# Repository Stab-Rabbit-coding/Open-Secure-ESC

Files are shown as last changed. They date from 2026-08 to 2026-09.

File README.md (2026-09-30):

# Open Source Trustworthy Electronic Speed Control

All builds:

MCU: **TI MSPM0G3518-Q1**, package RHB (VQFN-32, 5x5mm), orderable `M0G3518QRHBRQ1` [44] — pin map VERIFIED, standard package for all builds as of 2026-09-06 (`docs/solutions/architecture-patterns/bom-creepage-audit-can485-faraday.md` finding #1; supersedes the PM/LQFP-64 package, same die, ~4x smaller footprint). Supersedes the NXP S32K144 [31] as of 2026-08-10 (`TODO.md` §13.1; migration record in [`docs/HANDOFF-mcu-swap-s32k144-to-mspm0g3518.md`](docs/HANDOFF-mcu-swap-s32k144-to-mspm0g3518.md)), for its AES-128/256 accelerator with GCM/CMAC and hardware keystore, which lifted the AES-128 ceiling the S32K144's SHE-compliant CSEc imposed.

> **The two lines below still describe the S32K144 and its CSEc, which is no longer the MCU in any build.** They are left in place because the swap's *security* consequences are unfinished work, not a documentation lag — `docs/secure-element-architecture.md` has not yet been revisited (`TODO.md` §13.1.e), so rewriting the summary here would assert a conclusion nobody has reached. Treat every CSEc statement below as describing a superseded design until §13.1.e closes. The OPTIGA Trust M's role is unaffected: the MSPM0's AES engine is still symmetric, so the asymmetric layer is still required.

Message authentication: on-chip CSEc (Cryptographic Services Engine, SHE-compliant) security module built into the S32K144 [31] — no discrete TPM (the previously used Infineon SLB9672 [2] has been dropped from this design)
Root of trust: Infineon OPTIGA™ Trust M V3 secure element [45] over I²C (schematic `U2`) — device identity (ECDSA over a fab-provisioned key + X.509 certificate) and ephemeral session-key agreement (ECDHE). This is a secure element, **not** a TPM: it supplies the asymmetric layer CSEc structurally lacks, while CSEc keeps the per-frame AES-128 CMAC hot path. The split, and the 5 s security-monitor budget that forces it, are documented in [`docs/secure-element-architecture.md`](docs/secure-element-architecture.md)

Build Options:

* Motor speed sensor: ADC/DIO/SPI shaft sensor input (Hall / encoder / analog tach / magnetic absolute SSI-SPI, e.g. AEAT-8800-Q24 [64])
* Motor type: Brushed (Tier-1 integrated H-bridge DRV8874-Q1 [63]) / Brushless
* Holding brake: None (default) / Low-side solenoid driver, spring-applied (de-energised = engaged; TPL7407L [66]) — see `docs/decision-matrix.xlsx` "Holding Brake"
* Voltage: 2S, 4S, 6S, 8S, 12S
* Amperage: 10A, 20A, 30A, 40A, 50A, 80A, 120A
* Protocol: PWM, SBus, DBus, UART, TTL, SPI, RS-232 [3], RS-485 [4], CAN2.0 [5], CAN-FD [6], MIL-STD-1553B [7]
* Control: Open, Closed-Diff, Closed-PID
* EMI Hardening: None, Isolation, Grounding, Faraday
* Wire Egress: Opposite-end (default), Same-end opposite faces (both conductor groups leave one board end, phases on F.Cu and pack on B.Cu, shielded by the inner GND planes)
* Form Factor: Flat (default), Faceted rigid-flex (for mounting inside a curved host; strip width and sagitta derive from the host bore radius — see `docs/tools/strip_width.py`)
* Ingress & environmental protection: Splash/spray variants (target IPX4–IPX6, IEC 60529 [56]) air-cooled via an open aspirated path; Sealed/immersion variants (target IPX7–IPX8, up to NEMA 6P equivalent) shall use a metal conduction cooling path with no air exchange — these are two distinct mechanical designs, not one IP-rating dial (see `docs/design-waterproofing-and-thermal-management.md`).

## Repository layout

* `symbols/` — shared KiCad symbol library (one `.kicad_sym` per component),
  generated from citable pin specs; see `symbols/README.md`.
* `builds/<voltage>/<amperage>/<variant>/` — per-build instantiation of the
  axis options above: a descriptive `README.md` (BOM drawn from
  `docs/decision-matrix.xlsx`, with citations), a `kicad/` subfolder
  (schematic + shared-library wiring), and a `gerbers/` subfolder
  (fabrication output once a layout exists). Example:
  `builds/6s/50A/CAN_485_faraday/`.
* `docs/decision-matrix.xlsx` — per-axis BOM/workflow decision matrix that
  every build folder is generated from.
* `PROJECT_INDEX.md` — index of every active folder and file, with the
  conventions worth knowing before editing.

## License

Licensed under the CERN Open Hardware Licence Version 2 — Permissive
(CERN-OHL-P v2) [8]. See `LICENSE`.

## Governance

Contributions (human or AI) are governed by `AGENTS.md`. All citations
above are indexed in `REFERENCES.md`. Work is tracked in `TODO.md`.

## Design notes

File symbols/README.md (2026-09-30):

# symbols/ — Shared KiCad Symbol Library

Governed by `AGENTS.md`. One `.kicad_sym` file per component, generated (not
hand-edited) from a citable JSON pin spec. This folder is shared across every
`builds/<voltage>/<amperage>/<variant>/` build — a build's `kicad/` folder
references these files instead of re-deriving or re-drawing pinouts, which is
the token-optimized part of the workflow: sourcing a datasheet pinout once
here is reusable for every future build that needs the same part.

## Layout

```text
symbols/
  <PART>.kicad_sym      generated symbol library, one component per file
  specs/<PART>.json      pin spec the symbol was generated from (source of truth)
  tools/gen_kicad_symbol.py   generator: JSON spec -> .kicad_sym
```

Never hand-edit a `.kicad_sym` file directly (except cosmetic repositioning in
the KiCad Symbol Editor, which does not change pin numbers/names). If a pin
map changes, edit the JSON spec and regenerate:

```bash
cd symbols/tools
python3 gen_kicad_symbol.py ../specs/<PART>.json -o ..
```

Regenerate everything: `python3 gen_kicad_symbol.py ../specs/*.json -o ..`

Uses `kiutils` when it is installed (`pip install kiutils`; generated and round-trip-validated
against kiutils 1.4.8). When it is not importable the generator falls back to a
built-in S-expression emitter that writes the same file shape byte for byte
(checked 2026-09-17 against the committed `OPTIGA_TRUST_M` and `BLM15HD182SN1D`
symbols); validate the output with `kicad-cli sym export svg <PART>.kicad_sym` on
such machines.

## Adding a new component (the reusable part of this workflow)

1. Locate the component's primary datasheet (manufacturer PDF), per
   `AGENTS.md` SS1.1. If a local copy exists under `docs/datasheets/`, extract
   the pin table from it directly (e.g. with `pypdf`) rather than trusting
   memory or a secondary source.
2. Add/reuse a citation tag in `REFERENCES.md` per `AGENTS.md` SS2.
3. Write `symbols/specs/<PART>.json`:
   - `pins`: list of `{"num", "name", "etype", "side"}`. `etype` is a KiCad
     electrical pin type (`input`, `output`, `bidirectional`, `tri_state`,
     `passive`, `power_in`, `power_out`, `open_collector`, `no_connect`, ...).
     `side` is `left` / `right` / `top` / `bottom` — a layout hint, not a
     datasheet claim (rearrange freely in the KiCad Symbol Editor).
   - `citation`: REFERENCES.md tag(s), e.g. `"[9]"`.
   - `verification`: state plainly whether pin **numbers** came from a
     primary-source pin table (`VERIFIED`, cite page/table) or are
     placeholders because no primary source was reachable
     (`UNVERIFIED PLACEHOLDER PIN MAP`, per `AGENTS.md` SS1.3/SS3 — never
     silently presented as settled).
4. Run the generator, then round-trip-validate:

   ```bash
   python3 -c "from kiutils.symbol import SymbolLib; SymbolLib.from_file('../<PART>.kicad_sym')"
   ```

5. Reference the new file from the build's `kicad/sym-lib-table` (see below).

## Per-component status

| File | Citation | Pin-map status |
| --- | --- | --- |
| `S32K144.kicad_sym` | [31] | Feature-level facts VERIFIED; pin **numbers** UNVERIFIED PLACEHOLDER (local datasheet defers physical pinout to the S32K1xx Reference Manual, not obtained — see spec `verification` field, `TODO.md`) |
| `OPTIGA_TRUST_M.kicad_sym` | [45] | VERIFIED (full 10-pin PG-USON-10-2,-4 map, local datasheet p.17 Table 6). **Footprint deliberately blank** — no KiCad 9 standard footprint matches this 3×3 mm / 0.5 mm-pitch package; size one from p.15 Fig. 6 before layout |
| `ADM2582E_ADM2587E.kicad_sym` | [4], [9] | VERIFIED (full 20-pin); part selection itself still "Candidate" in `docs/decision-matrix.xlsx` |
| `ADM3055E_ADM3057E.kicad_sym` | [6], [10] | VERIFIED (full 20-pin); part selection itself still "Candidate" |
| `MSPM0G3518_Q1_RHB_TILT.kicad_sym` | [44] | VERIFIED (all 32 RHB pins, [44] Fig. 6-6 / Table 6-2 read 2026-09-17); the RHB MCU with pins named by their role in `builds/6s/10A/BRUSHED_CAN_485_isolation/` — includes PA7/PA22/PA26/PA27, which `MSPM0G3518_Q1_RHB` omits |
| `DRV8874_Q1.kicad_sym` | [62], [63] | VERIFIED (full 16-pin PWP map, [63] Sec. 5, cross-checked against [62]); footprint `Open_Secure_ESC:TI_PWP0016J_…` from TI's own land-pattern sheet (`tools/gen_ti_powerpad_footprints.py`). Tier-1 brushed bridge, first used by `builds/6s/10A/BRUSHED_CAN_485_isolation/` |
| `TPS54560B.kicad_sym` | [65] | VERIFIED (full 8-pin DDA map, [65] Sec. 5); footprint `Open_Secure_ESC:TI_DDA0008B_…` from TI's land-pattern sheet. Motor-rail buck of the 6S/10A brushed build; inductor/diode/compensation not selected by the spec |
| `TPL7407L.kicad_sym` | [66] | VERIFIED (full 16-pin map, [66] Sec. 5); footprint is KiCad stock `Package_SO:TSSOP-16_4.4x5mm_P0.65mm` checked against the PW outline (JEDEC MO-153 IPC land, flagged per AGENTS.md Sec. 4). Brake-solenoid low-side driver |
| `AEAT_8800_Q24.kicad_sym` | [64] | VERIFIED (full 24-pin map, [64] Pinout Description; EP = VSS not modelled as a pin); footprint is KiCad stock `Package_DFN_QFN:QFN-24-1EP_5x5mm_P0.65mm_EP3.25x3.25mm` checked against [64] Fig. 16 dimensions; Broadcom's own land pattern (Fig. 17, raster) NOT verified — TODO.md 18.5. Off-board sensor daughter part |
| `DRV8353S.kicad_sym` | [21] | VERIFIED (full 40-pin, RTA/WQFN package; local datasheet). **2026-08-15: pin 41 `PAD` added** for the exposed thermal pad, tied to GND — without it the footprint's pad 41 imported with no net, i.e. an isolated copper island under the power stage. The GND assignment is an engineering default, not a datasheet value. Footprint now `Open_Secure_ESC:TI_RTA0040B_WQFN-40_6x6mm_P0.5mm_EP4.15x4.15mm` |
| `INA240.kicad_sym` | [22] | VERIFIED (full 8-pin, D/SOIC-8 package; local datasheet) |
| `IRFB4110PBF.kicad_sym` | [20] | Standard TO-220AB G/D/S pinout convention; ratings VERIFIED (local datasheet) |
| `WSLP2512.kicad_sym` | [23] | Generic 2-terminal chip pinout; values VERIFIED (local datasheet) |
| `INR21700_P42A.kicad_sym` | [14] | Generic 2-terminal cell pinout; values VERIFIED (local datasheet) |
| `WE_SHC_3671375.kicad_sym` | [15], [19] | Mechanical shield **cover** — no functional schematic pins (placeholder GND-bond pin only); dimensions VERIFIED (local datasheet); pairs with the frame below. **Intentionally has NO footprint**: the cover clips onto the frame and is not soldered, so its datasheet publishes no land pattern. Placed on schematics as BOM-only, excluded from the board |
| `WE_SHC_3670375.kicad_sym` | [15], [19], [30] | Mechanical shield **frame** — the piece actually soldered; dimensions VERIFIED (local datasheet). Footprint `Open_Secure_ESC:Wurth_WE-SHC_3670375_Frame_29.3x37.5mm` reproduces Wurth's own Recommended Land Pattern |

"UNVERIFIED PLACEHOLDER" pin maps shall not be sent to fab — see each
`specs/*.json` `verification` field and `TODO.md` 1.10 for what would need to
be resolved first (a working fetch path or a manually obtained primary PDF).

**2026-08-03: MCU/TPM swap.** `MSPM0G3507.kicad_sym`/`specs/MSPM0G3507.json`
(project MCU, REFERENCES.md [1]) and `SLB9672.kicad_sym`/`specs/SLB9672.json`
(external TPM, REFERENCES.md [2]) were removed from this folder. The project
MCU changed to the NXP S32K144 (`S32K144.kicad_sym`, [31] above), whose
on-chip CSEc security module now provides message authentication in place of
the discrete SLB9672 TPM — see root `README.md` and
`builds/6s/50A/CAN_485_faraday/README.md`. Both REFERENCES.md entries [1]
and [2] are retained (never repurposed, per `AGENTS.md` §2.5) and marked
superseded/dropped there; their local datasheet PDFs under
`docs/datasheets/` are also kept so those citation records stay resolvable.

**2026-08-09: secure element added (not a TPM reinstatement).**
`OPTIGA_TRUST_M.kicad_sym`/`specs/OPTIGA_TRUST_M.json` ([45], Infineon
OPTIGA™ Trust M V3, sales code SLS 32AIA010ML) joins this library. It is an
**I2C secure element, a different device class from the dropped SLB9672
TPM 2.0** ([2]) — it is adopted for the asymmetric PKI capability the
S32K144's symmetric-only CSEc structurally cannot provide, and it runs
*alongside* CSEc rather than replacing it. The 2026-08-03 decision above
stands: CSEc still owns per-frame message authentication. See
`docs/secure-element-architecture.md`.

Housekeeping done in the same pass: `SLB9672_TPM.kicad_sym` was deleted.
That file was an orphan — the 2026-08-03 note above already declared the
SLB9672 symbol removed, and no `specs/SLB9672.json` exists, so the file
could not be regenerated, was referenced by nothing, and contradicted both
this README and `REFERENCES.md` [2]. Removing it makes the tree match what
those two documents already said.

## footprints/ — this repo's own land patterns

`footprints/Open_Secure_ESC.pretty/` holds footprints for packages KiCad 9.0
does not ship. Each one is generated by a script in `tools/`, and each
script's docstring records exactly which drawing every dimension came from
and which numbers are derivations rather than manufacturer values — the same
standard `specs/*.json` applies to pin maps.

| Footprint | For | Source of the land pattern |
| --- | --- | --- |
| `Infineon_PG-USON-10-2-4_3x3mm_P0.5mm_EP1.7x2.5mm` | OPTIGA Trust M (U2) | Package dimensions from [45] p.15 Fig. 6. Infineon publishes **no** land pattern, so the fillets are an **IPC-7351-style derivation** — an engineering judgment call per `AGENTS.md` §4 |
| `Texas_DGS0028A_VSSOP-28_3x7.1mm_P0.5mm` | superseded MCU package | TI package drawing |
| `TI_RTA0040B_WQFN-40_6x6mm_P0.5mm_EP4.15x4.15mm` | DRV8353S gate driver (U5) | **TI's own** EXAMPLE BOARD LAYOUT and EXAMPLE STENCIL DESIGN sheets, drawing 4219112/A in [21] — manufacturer values, not a derivation |
| `Wurth_WE-SHC_3670375_Frame_29.3x37.5mm` | Faraday shield frame (SH1) | **Wurth's own** Recommended Land Pattern, [30] p.1 rev. ViM 002.000 — manufacturer values. Hole *plating* is the one engineering default |

Two of these land patterns are printed as vector drawings whose callouts do
not survive `pdftotext`. Where that happened the sheet was rendered at
300–400 dpi and measured, and the reading was then **cross-checked against an
independent dimension on the same drawing** rather than trusted on its own —
see each generator's docstring for the specific checks. That cross-check is
what separates a measured value from a guessed one under `AGENTS.md` §1.3.

**Toshiba land patterns live in the CATALOG, not the datasheet.** The
TPHR8504PL part datasheet has no land pattern -- all 10 pages were searched
and the words "land", "mounting" and "recommend" do not appear. Toshiba
publishes them in the *MOSFET Product Catalog* (REFERENCES.md [50], local
copy `docs/datasheets/TPHR8504PL_catalog_20260706_ALQ00024.pdf`), whose
**p.46 "Surface Mount Type"** tabulates package dimensions and land patterns
side by side for the whole surface-mount family -- DSOP Advance(WF)L/M, SOP
Advance, SOP Advance(N), SOP Advance(E), SOP Advance(EWF). Use it for **any**
Toshiba MOSFET package this repo adopts; do not derive one from the package
drawing when the catalog has the real figure. The first pass at
`gen_tphr8504pl_footprint.py` did derive one IPC-7351-style, and it was 46%
short on drain-land area and 86% short on lead-pad area against Toshiba's
published values.

**Watch the reference datum.** TI's RTA0040B sheet dimensions `2X (5.8)` as
the **centre-to-centre** distance between opposite pad rows, not the outer
copper extent. Reading it as the outer extent moves every pad 0.3 mm inward
and overlaps the corner pads — a dead short between pin 1 (CPL) and pin 40
(VGLS). DRC caught it; inspection had not.

## Open_Secure_ESC_Generic.kicad_sym — generic support symbols

R, C, C_Polarized, Conn_01x02/03/04 and PWR_FLAG, as authored by
`builds/*/kicad/tools/genlib.py`. These had previously been stored in
schematics under KiCad's own `Device:`, `Connector_Generic:` and `power:`
library names even though their pin geometry differs from KiCad's parts
(`Device:R` pin 1 sits at y = 6.35 here against y = 3.81 in KiCad 9.0),
which made every placed instance raise a `lib_symbol_mismatch`. They live
here now so that a schematic matches the library it names. Their *values*
remain engineering defaults, not datasheet-sourced.

## Using this library from a build

Add a project-relative library table entry (see
`builds/6s/50A/CAN_485_faraday/kicad/sym-lib-table` for a working example)
pointing at this shared folder. `${KIPRJMOD}` is the folder containing the
`.kicad_pro`/`.kicad_sch`; for a build at
`builds/<voltage>/<amperage>/<variant>/kicad/`, that is 5 levels above
`symbols/`:

```text
(lib (name "open_secure_esc")(type "KiCad")(uri "${KIPRJMOD}/../../../../../symbols/S32K144.kicad_sym")(options "")(descr ""))
```

One `(lib ...)` line per `.kicad_sym` file needed by that build — do not copy
symbol files into a build folder; reference the shared copy so a pin-map
correction only has to happen once.

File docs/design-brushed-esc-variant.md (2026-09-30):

# Design Decision: Brushed ESC Variant — Physical and Firmware Integration

Status: DRAFT (authoring complete) — **first instance built 2026-09-17:** `builds/6s/10A/BRUSHED_CAN_485_isolation/` (Tier-1 integrated H-bridge DRV8874-Q1 [63]; schematic + BOM readiness, `TODO.md` §18). That build's README resolves the fail-safe question below for itself (brake engaged, motor coasting) and carries the brushed firmware requirements.
Applies to: Brushed-ESC build variants (new branch of builds)
Governing rules: AGENTS.md §1–§3 — verify all part claims against primary datasheets; mark `UNVERIFIED` when not available.

Summary

- Provide a design decision record describing how the brushed-ESC variant differs from brushless designs at the schematic, BOM, PCB, and firmware levels, and document safety/protection specifics.

Why support brushed motors

- Brushed motors remain common in many industrial and hobbyist use cases; supporting a dedicated H-bridge variant increases product applicability. Brushed variant simplifies commutation logic but requires careful H-bridge and protection design.

Electrical architecture (high level)

- Replace 3-phase inverter drive + gate-driver stage with a single H-bridge (half-bridge pair) sized for target amperage tier.
- Provide current sensing, dead-time control, and flyback/clamping protection appropriate for inductive motor loads and regenerative events.
- Include direction control signal and PWM input (single channel + direction) in firmware mapping.

Power-stage components & protection (to be VERIFIED)

- H-bridge MOSFETs or integrated H-bridge ICs sized per amperage tier. Tier 1 (2S–6S, 10–20 A) is now the TI DRV8874-Q1 [63] (datasheet local, VERIFIED); Tier-2/3 discrete-FET candidates remain UNVERIFIED until their datasheets are added (see `docs/OpenSecureESC-Brushed-Specifications.md` §1).
- Freewheeling / flyback diodes or synchronous MOSFET conduction strategy: the design shall handle regenerative currents; include regenerative path to bus or clamp/regulator and report to firmware.
- RC snubbers, TVS for transients, and precharge/soft-start for large motor inductance loads.
- Current sensing: shunt + amplifier or integrated current-sense filter placement to provide overcurrent detection and closed-loop current limit.

Schematic & PCB layout notes

- H-bridge placed close to power connectors; copper pour for heat dissipation.
- Thermal considerations: footprint for thermal vias, heatpad and heatsink provision.
- Keep sensitive analog/logic routing (speed-sensor, ADC, encoder lines) physically separated and shielded from switching nodes and gate traces.
- Provide component footprints and mechanical constraints in `builds/<voltage>/<amperage>/BRUSHED_<variant>/kicad/`.

Firmware implications

- Add brushed control code path:

  - PWM + direction mapping
  - Closed-loop speed control via speed sensor (see design-speed-sensor-integration.md)
  - Current-limiting and regenerative handling logic
  - Dead-time configuration and MOSFET gate timing safe defaults

- Define test vectors and unit tests for:

  - Direction change safety (ensure motor spins down or safe transition)
  - Short-circuit and overcurrent cutoff behavior
  - Regeneration absorption/limiting

Safety & failure modes

> **CAUTION:** H-bridge cross-conduction (shoot-through) drives simultaneous high-side/low-side
> conduction, which can destroy the power MOSFETs within microseconds and presents a fire risk
> from the resulting overcurrent. Cross-conduction detection shall hard-disable PWM immediately
> on assertion; do not rely on current-sense overthreshold handling alone to catch this case.

- Define safe-state on faults (fail-safe vs fail-operational decision required; reference to `TODO.md` 12.3 and project safety requirements).
- On MOSFET cross-conduction detection: hard disable PWM and assert fault.
- On current-sense overthreshold: limit duty cycle, then trip if persists.

Acceptance checklist (before layout/fab)

- H-bridge ERC clean
- Current-sense integrated and validated in schematic
- Dead-time validated in simulation/tooling
- Thermal analysis for MOSFETs and heatsinking
- Firmware test harness for brushed flow
- BOM lines for H-bridge parts present and each has a `REFERENCES.md` entry (IEEE format)

Testing & verification

- Bench test: H-bridge switching, measured dead-time and shoot-through current, regen absorption behavior, thermal soak tests.
- HIL test: closed-loop speed under disturbance and sensor-failure scenarios.

References & verification

- All H-bridge device claims and power-handling assertions shall carry primary datasheet citations in `REFERENCES.md` before merging. Any design value not verified shall be annotated `UNVERIFIED — needs primary source`.

Authored-by: repo maintainers; see AGENTS.md for contributor rules.

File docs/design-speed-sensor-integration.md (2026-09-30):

# Design Decision: Motor Speed Sensor — Physical Integration

Status: DRAFT (authoring complete)
Applies to: All build variants (Brushed + Brushless)
Governing rules: AGENTS.md §1–§3 — every technical claim that requires a primary source shall be verified and added to REFERENCES.md; UNVERIFIED markers applied where the repo lacks the primary source.

Summary

- Requirement: every ESC variant shall provide a motor-speed input interface (Hall / optical encoder / analog tachometer) as a first-class item in BOM and schematic. This doc defines electrical integration, connector choices, front-end protection, PCB routing and layout notes, failure modes, and test points.

Rationale

- Closed-loop speed control and safe transitions between sensorless and sensor-based operation require an explicit per-vehicle sensor input. For high-safety systems, hardware-level detection and robust wiring reduce failure modes and improve testability.

Interfaces supported (prioritized)

1. Hall-effect (digital)

   - Typical use: 3-wire Hall (Vcc / GND / open-collector pulse) or single digital pulse per revolution.
   - MCU side: digital input with interrupt; optional Schmitt/differential input if using differential buffer.
   - Electrical front-end:

     - Series resistor (e.g., 1–10 kΩ) + pull-up to 3.3 V on MCU side (value: UNVERIFIED — choose per sensor datasheet).
     - Optional small RC to filter EMI on signal (time constant chosen to preserve maximum RPM edge frequency).
     - ESD protection (TVS diode to 3.3 V/GND) and clamping diodes where appropriate.

   - Connector: 3-pin keyed JST shrouded (VCC, GND, SIG) on board; add testpoint for SIG.

2. Quadrature encoder (optical / magnetic)

   - Typical use: two channels A/B ±index; TTL-level/RS422-style differential outputs for long cable runs.
   - MCU side: hardware quadrature timer input(s) where available; else ISR-based decode with minimal jitter.
   - Electrical front-end:

     - If sensor outputs are differential (RS422), provide small differential receiver (e.g., comparator/line receiver) or use MCU differential-capable inputs.
     - Level-shift circuit when 5 V encoder used (use resistor divider or proper level-shifter IC).
     - EMI filtering and twisted-pair wiring required; common-mode choke optional for long runs.
     - ESD protection and TVS diodes on each channel.

   - Connector: 4–6 pin (A, B, Index, Vcc, Gnd, Shield optional); keyed header recommended.

3. Analog tachometer (voltage proportional to speed)

   - Typical use: legacy analog tach outputs (0–Vpeak).
   - MCU side: routed to an ADC channel, preceded by anti-alias low-pass filter and input protection circuit.
   - Electrical front-end:

     - Input attenuation / offset circuit if signal is bipolar (use op-amp level shift).
     - Anti-alias filter (order and cutoff set to twice expected rotation fundamental; exact values UNVERIFIED until spec).
     - Over-voltage protection clamp and TVS.
     - Sample and hold / averaging in firmware; calibration routine required.

   - Connector: 2–3 pin (SIG, GND, Shield optional).

Connector & mechanical

- Use keyed, shrouded connectors with clear polarity (e.g., JST SH series or Molex MicroLock) sized to mechanical/ambient needs.
- Include shield lug on connector and tie to chassis ground only at a single point as per grounding policy (add to layout checklist per EMI tier).
- Provide a testpoint per sensor signal for bench verification.

Pin assignment & MCU resources

- Reserve:

  - At least 2 GPIO/interrupt-capable pins for Hall/encoder (more for quadrature index).
  - 1 ADC channel for analog tach plus an op-amp if signal conditioning required.
  - Optional spare timer/quadrature hardware channel depending on MCU peripheral count.

- Implementation note: exact pin numbers are UNVERIFIED until `symbols/specs/MSPM0G3518_Q1_PM.json` and primary pinmap are finalized — update when available (Cn).

Protection & EMI

- All sensor inputs receive:

  - Series resistor
  - ESD/TVS clamp sized for automotive/industrial environment (choose per EMI/ESD targets; UNVERIFIED until selected).
  - Common-mode filtering for long runs (differential receiver or choke).
  - Input low-pass filtering where analog sampling is used.

- Layout:

  - Route sensor lines away from high-current power traces and MOSFET switching nodes.
  - Place op-amps and ADC decoupling close to MCU ADC pins.
  - For quadrature/differential signals use controlled-impedance, matched-length pairs where speeds/edge timing require it.

Failure modes & safety

- Detect open, short-to-rail, and stalled sensor conditions in firmware:

  - Hall/encoder: loss of pulses → enter safe fallback (sensorless or reduced-power mode) or to predefined safe-state per safety policy (2.2). Behavior shall be defined by the system integrator.
  - Analog tach: out-of-range voltage → fault.

- Watchdog and cross-check: compare RPM reported by sensor with motor-modelled RPM (if sensorless estimator exists); on mismatch exceed threshold → fault.
- All failure-handling policies shall be recorded and linked to the AGENTS.md checklist before merging.

Testing

- Provide bench test vectors:

  - Pulse-rate verification (Hall)
  - Quadrature phase correctness (A leads B vs B leads A)
  - ADC scale/offset calibration (analog)

- Include HIL tests for noise immunity and EMI injection tests.

References & verification

- Trace sensor front-end component choices and filter corner values to component datasheets and EMI standards (add entries to `REFERENCES.md` with IEEE format). Mark values UNVERIFIED until primary-source citations added.

Authored-by: repo maintainers; see AGENTS.md for contributor rules.

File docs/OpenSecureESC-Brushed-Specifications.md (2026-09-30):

# Open-Source Hardware Brushed ESC Platform Architectural & Component Framework

## Executive Summary

> **Citation status (2026-09-17).** This document's own bibliography (§References) is
> not integrated into `REFERENCES.md` and cites secondary mirrors; per `AGENTS.md` §1.1
> only claims re-verified from a primary datasheet held in `docs/datasheets/` may be
> relied on. Re-verified so far: the Tier-1 bridge, now the **DRV8874-Q1** —
> `REFERENCES.md` [62]/[63], first instance `builds/6s/10A/BRUSHED_CAN_485_isolation/`.
> Correction from that verification: §2.2's "integrated 45 mΩ (total H-bridge)" is not
> what the datasheet states — [63] §6.5 gives **100 mΩ typ / 120 mΩ max per high-side
> and per low-side FET** (≈ 200 mΩ HS+LS, 240 mΩ worst case). Everything else in §1–§4
> stays as originally drafted until re-verified.

This document defines a scalable, OSHWA-certifiable (Open Source Hardware Association) Electronic Speed Controller (ESC) architecture designed for brushed DC motors. The framework scales across operating voltages from **2S to 12S LiPo (8.4V – 50.4V)** and continuous current loads from **10A to 120A+**.
To avoid re-engineering core system logic, all framework variants share a unified digital and security architecture:

- **Microcontroller Unit (MCU):** Texas Instruments MSPM0G3518-Q1
- **Root of Trust / Security Element:** Infineon OPTIGA™ Trust M V3 (utilizing $I^2C$ Shielded Connection)

Additionally, this framework specifies an adaptable thermal topology supporting both open-frame **Air (Finned)** cooling and sealed **Conductive Strip (Marine)** cooling, along with strict component sourcing guidelines to ensure supply chain compliance and eliminate single-source dependencies on restricted entities.

## 1. Modular Power Tier Topologies

A single monolithic H-bridge driver cannot cover the entire range from 2S/10A (84W) to 12S/120A (6,000W+) efficiently. The framework establishes three power-tier topologies while keeping pinout configurations and firmware abstractions consistent.

| Feature / Metric | Tier 1 (Low Power) | Tier 2 (Mid Power) | Tier 3 (High Power) |
| :---- | :---- | :---- | :---- |
| **Voltage Range** | 2S – 6S (8.4V – 25.2V) | 2S – 8S (8.4V – 33.6V) | 2S – 12S (8.4V – 50.4V) |
| **Current Rating** | 10A – 20A Continuous | 20A – 60A Continuous | 60A – 120A+ Continuous |
| **Topology** | Monolithic IC H-Bridge | Discrete N-FETs + Integrated Gate Driver | Discrete High-V N-FETs + Dual Drivers |
| **Primary Driver / Bridge** | TI DRV8873-Q1 / DRV8874 | TI DRV8706-Q1 | TI DRV8718-Q1 / ADI LTC7000A |
| **Power MOSFETs** | Integrated Internal FETs | Infineon IPT012N08N5 (HSOF-8) | Infineon IPT015N10N5 / Vishay SUM70042E |
| **Current Sensing** | Integrated Driver Analog Output | Low-Side Shunt + Internal MCU OPA | Inline Phase Shunt / Dedicated CSA |
| **Target Application** | Robotics, Aux Drives, Small Rovers | Medium UGVs, Heavy Actuators | Heavy UGVs, Marine Thrusters, Winches |

## 2. Integrated Circuit & Active Silicon Specifications

### 2.1 Microcontroller & Security Root of Trust

- **MCU: TI MSPM0G3518-Q1**
  - Arm® 32-bit Cortex®-M0+ running at up to 80 MHz.
  - Integrated advanced control PWM timers, high-speed 12-bit ADCs, zero-drift Operational Amplifiers (OPAs), and Analog Comparators (COMPs).
- **Root of Trust: Infineon OPTIGA™ Trust M V3**
  - Common Criteria EAL6+ certified hardware security controller.
  - Secure key storage, cryptographic identity verification, and anti-tamper authentication for firmware integrity and device pairing.

### 2.2 Tier 1: Integrated H-Bridge IC Options (2S – 6S / 10A – 20A)

- **TI DRV8873-Q1 / DRV8874:**
  - 38V operating supply maximum rating, integrated 45 mΩ (total H-bridge) $R_{DS(on)}$ power MOSFETs. **Corrected 2026-09-17 against [63] §6.5 (DRV8874-Q1): 4.5–37 V operating, 100 mΩ typ / 120 mΩ max per FET (HS and LS each), 6 A peak — see the citation-status note above.**
  - Features direct PWM/PH-EN interfaces, integrated current sensing proportional output, and comprehensive protections (OCP, TSD, UVLO).

### 2.3 Tier 2 & Tier 3: Discrete MOSFET & Gate Driver Options

- **Smart Gate Drivers:**
  - **TI DRV8706-Q1 (Tier 2):** 37V operating gate driver with integrated current sense amplifier, programmable gate drive currents (for EMI tuning), and charge pump.
  - **TI DRV8718-Q1 (Tier 3):** Automotive 40V, 8-channel smart gate driver with integrated wide common-mode inline current sense amplifiers.
  - **ADI LTC7000A (Tier 3 Alternative):** High-side N-channel MOSFET gate driver operating up to 135V, featuring an internal charge pump for 100% duty-cycle operation and adjustable overcurrent protection.
- **Discrete N-Channel Power MOSFETs:**
  - **Infineon IPT012N08N5 (80V, 1.2 mΩ, HSOF-8):** OptiMOS 5 Power Transistor, 80V breakdown voltage, 1.2 mΩ maximum $R_{DS(on)}$, 400A continuous drain current ($T_C=25^\circ\text{C}$), in an HSOF-8 (TO-LL) package.
  - **Infineon IPT015N10N5 (100V, 1.5 mΩ, HSOF-8):** OptiMOS 5 Power Transistor, 100V breakdown voltage, 1.5 mΩ typical / 1.6 mΩ maximum $R_{DS(on)}$, 300A continuous drain current ($T_C=25^\circ\text{C}$), in an HSOF-8 package.
  - **Vishay SUM70042E (100V, 4.0 mΩ, TO-263 / D²PAK):** N-Channel 100V TrenchFET power MOSFET, 4.0 mΩ maximum $R_{DS(on)}$ at $V_{GS}=10\text{V}$, 150A continuous drain current in a surface-mount / hand-solderable TO-263 package.
  - **Infineon IPB072N15N3G (150V, 7.2 mΩ, TO-263):** OptiMOS 3 Power Transistor, 150V breakdown voltage, 7.2 mΩ maximum $R_{DS(on)}$ in a TO-263 package.

## 3. Dual Cooling Thermal Implementation Strategy

To allow a single printed circuit board (PCB) design to serve open-air and sealed/marine applications, the physical component layout uses a top-bottom functional separation.

### 3.1 PCB Layout Strategy

1. **Top Side:** MCU, OPTIGA Trust M V3, gate drivers, passive filters, communications (CAN/RS485/UART), and signal routing.
2. **Bottom Side:** Power MOSFETs (HSOF-8 or D²PAK) and high-current power traces.
3. **Thermal Via Array:** A matrix of 0.3mm plugged/capped thermal vias under all MOSFET drain pads, transferring heat efficiently across internal 2oz or 3oz copper layers.

### 3.2 Thermal Interface Architectures

```text
AIR COOLED (OPEN FRAME / FINNED)          SEALED / MARINE (CONDUCTIVE STRIP)

+-----------------------------------+     +-----------------------------------+
|  Top Components, MCU & Logic      |     |  Top Components, MCU & Logic      |
+-----------------------------------+     +-----------------------------------+
|  PCB (4-Layer, 2oz/3oz Copper)    |     |  PCB (4-Layer, 2oz/3oz Copper)    |
+-----------------------------------+     +-----------------------------------+
| Bottom MOSFETs (Bare Thermal Pad) |     | Bottom MOSFETs (Bare Thermal Pad) |
+-----------------------------------+     +-----------------------------------+
| Thermal Gap Pad (1.5mm - 3.0mm)   |     | High-K Thermal Interface Pad      |
+-----------------------------------+     +-----------------------------------+
| Anodized Aluminum Finned Heatsink |     | Aluminum/Copper Spreader Bar      |
+-----------------------------------+     +-----------------------------------+
                                          | Sealed Enclosure / Cold Plate     |
                                          +-----------------------------------+
```

- **Air Cooling (Open Frame):** Anodized aluminum finned heatsink mounted to the bottom layer via an electrically insulating thermal gap pad.
- **Conductive Strip Cooling (Marine / Sealed):** Flat aluminum or copper spreader plate bolted directly against the MOSFET thermal pad array. Heat transfers from the spreader plate to the vessel hull, chassis, or liquid cold-plate.
- **Environmental Protection:** Conformal coating (IPC-CC-830 acrylic or silicone) applied across top-side logic components, leaving bottom thermal contact surfaces uncoated.

## 4. Supply Chain Compliance & Component Origin Verification

To satisfy supply chain standards (e.g., NDAA Section 889, DFARS 252.225-7007, EAR/ITAR rules), active components shall not originate from restricted entity lists or covered regions (primarily China and Russia).

### 4.1 Active Component Sourcing & Fab Compliance Matrix

| Component | Function / Spec | Vendor | Wafer Fab / Primary Diffusion | Assembly & Test Facility | Compliance Status |
| :---- | :---- | :---- | :---- | :---- | :---- |
| **MSPM0G3518-Q1** | Primary Microcontroller | Texas Instruments (USA) | USA / Japan | Malaysia / Taiwan / Thailand | **Compliant** |
| **OPTIGA™ Trust M V3** | Root of Trust Security | Infineon (Germany) | Germany / Austria | Malaysia / Philippines | **Compliant** |
| **DRV8873-Q1 / DRV8874** | Integrated H-Bridge IC | Texas Instruments (USA) | USA (Dallas, TX) | Taiwan / Malaysia | **Compliant** |
| **DRV8706-Q1** | Smart Gate Driver (37V) | Texas Instruments (USA) | USA | Taiwan / Philippines | **Compliant** |
| **DRV8718-Q1** | Multi-Channel Driver | Texas Instruments (USA) | USA | Taiwan / Malaysia | **Compliant** |
| **LTC7000A** | High-Side Gate Driver (135V) | Analog Devices (USA) | USA (CA / WA) | Malaysia / Philippines | **Compliant** |
| **L6387E** *(Excluded)* | Gate Driver (*Alternative*) | STMicroelectronics (EU) | Italy / France | Shenzhen, China | ⚠️ **Non-Compliant** (Backend in China) |
| **IPT012N08N5** | MOSFET 80V, 1.2mΩ | Infineon (Germany) | Austria / Germany | Malaysia / Germany | **Compliant** |
| **IPT015N10N5** | MOSFET 100V, 1.5mΩ | Infineon (Germany) | Austria / Germany | Malaysia / Germany | **Compliant** |
| **SUM70042E** | MOSFET 100V, 4.0mΩ | Vishay Siliconix (USA) | USA (Santa Clara, CA) | Israel / Taiwan | **Compliant** |
| **IPB072N15N3G** | MOSFET 150V, 7.2mΩ | Infineon (Germany) | Austria / Germany | Malaysia | **Compliant** |

### 4.2 Procurement & Design Verification Rules

1. **Driver Standardization:** The STMicroelectronics L6387E (up to 600V driver) is explicitly excluded due to backend packaging in China. All gate drivers are standardized on Texas Instruments (DRV series) and Analog Devices (LTC series) components.
2. **Traceability:** Prior to manufacturing, production runs require a Certificate of Origin (COO) for all silicon lots from authorized distributors (e.g., Arrow, Mouser, Digi-Key).
3. **OSHWA Certification Alignment:** All schematic, Gerber, and BOM files shall publish full manufacturing part numbers (MPNs) alongside verified non-restricted distributor SKUs.

## References

[1] Texas Instruments, "DRV8718-Q1 Automotive 40-V 8-Channel Smart Gate Driver Datasheet," TI.com. [Online]. Available: [https://www.ti.com/product/DRV8718-Q1](https://www.ti.com/product/DRV8718-Q1)
[2] Analog Devices, "LTC7000A High Voltage High-Side N-Channel MOSFET Driver Datasheet," Analog Devices Inc. [Online]. Available: [https://www.analog.com/en/products/ltc7000a.html](https://www.analog.com/en/products/ltc7000a.html)
[3] STMicroelectronics, "Power Management Guide (L6387E Technical Reference)," ST.com. [Online]. Available: [https://www.st.com/resource/en/brochure/power-management-guide.pdf](https://www.st.com/resource/en/brochure/power-management-guide.pdf)
[4] Infineon Technologies AG, "OptiMOS™ 5 Power-Transistor IPB020N08N5 / IPT Series 80V Datasheet," Infineon.com. [Online]. Available: [https://www.infineon.com/assets/row/public/documents/24/49/infineon-ipb020n08n5-datasheet-en.pdf](https://www.infineon.com/assets/row/public/documents/24/49/infineon-ipb020n08n5-datasheet-en.pdf)
[5] Infineon Technologies AG, "IPT015N10N5 OptiMOS™ 5 Power MOSFET 100V Datasheet," Rev. 2.2. [Online]. Available: [https://www.mouser.com/datasheet/2/196/Infineon-IPT015N10N5-DS-v02_02-EN-1731931.pdf](https://www.mouser.com/datasheet/2/196/Infineon-IPT015N10N5-DS-v02_02-EN-1731931.pdf)
[6] Vishay Siliconix, "SUM70042E Automotive N-Channel 100 V (D-S) 175 °C MOSFET Datasheet," Document No. 63052. [Online]. Available: [https://www.vishay.com/doc/?63052](https://www.vishay.com/doc/?63052)
[7] Infineon Technologies AG, "IPB072N15N3 OptiMOS™ 3 Power-Transistor 150V Datasheet," Datasheet4U. [Online]. Available: [https://datasheet4u.com/datasheets/Infineon/IPB072N15N3/1455785](https://datasheet4u.com/datasheets/Infineon/IPB072N15N3/1455785)
[8] U.S. General Services Administration, "Acquisition.gov NDAA Section 889 Policies & Regulations," Acquisition.gov. [Online]. Available: [https://www.acquisition.gov/Section-889-Policies](https://www.acquisition.gov/Section-889-Policies)
[9] Defense Acquisition Regulations System, "DFARS 252.225-7007: Prohibition on Acquisition of Certain Items from Communist Chinese Military Companies," Cornell Law / Acquisition.gov. [Online]. Available: [https://www.law.cornell.edu/cfr/text/48/252.225-7007](https://www.law.cornell.edu/cfr/text/48/252.225-7007)

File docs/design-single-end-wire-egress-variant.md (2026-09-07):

# Single-End Wire Egress Variant — design plan

Governed by [`AGENTS.md`](../AGENTS.md). Tracked as `TODO.md` §15.
Decision-matrix axis: **Wire Egress**, value `Same-end, opposite faces`.

**Status: PARTLY IMPLEMENTED as of 2026-08-31, not vetted for fabrication.**
Geometry is applied in `builds/6s/50A/CAN_485_faraday_sameend/` (DRC 20
warnings / 0 errors / 150 unconnected under KiCad 9.0.2); routing, stackup
(§2.2) and VM distribution to the relocated pack pad (§3.2) are **not** done.
The partition first proposed in §3.3 was measured and **failed** — see §3.3
for what was built instead. Every quantitative
claim below is either (a) read directly out of the as-built
`builds/6s/50A/CAN_485_faraday/kicad/*.kicad_pcb`, (b) produced by a repo tool
named at the point of use, (c) arithmetic shown in full at the point of use,
or (d) explicitly marked `UNVERIFIED — needs primary source (see TODO.md)`
per `AGENTS.md` §3.

**Authorship.** Drafted by **Claude Opus 5** (Anthropic), 2026-08-31, at the
direction of the repository owner (GitHub: `Stab-Rabbit-coding`). Revised the
same day after the owner confirmed the opposite-**faces** reading. No portion
was authored by another model. Reviewed by: *nobody yet — this plan has not
been through human review.*

**Units.** Human-facing dimensions are imperial-primary with metric in
parentheses, per the project-wide convention. KiCad-native coordinates are
quoted in millimetres exactly as they appear in the board file, because they
are literal file values rather than measurements — converting them would
break traceability back to the `.kicad_pcb`.

---

## 1. The requirement

The ESC is installed in a **pocket** — a blind cavity in a structure — where
all five power conductors must leave through the **same open end**.

**Resolved 2026-08-31 by the repository owner: "opposite sides" means
opposite *faces* — front and back copper — in order to keep separation
between the two conductor groups.** The earlier long-edge reading is
withdrawn; it is retained only as rejected alternative §9.2.

| Conductor | Net | Count | Face |
| --- | --- | --- | --- |
| Motor phases | `PH_A` / `PH_B` / `PH_C` | 3 | **F.Cu** (unchanged) |
| Pack positive | `VM` (VBATT+) | 1 | **B.Cu** |
| Pack return | `GND` (VBATT−) | 1 | **B.Cu** |

§3 derives that face assignment rather than assuming it.

---

## 2. The as-built baseline

Read from
`builds/6s/50A/CAN_485_faraday/kicad/open_secure_esc_6s_50a_can485_faraday.kicad_pcb`
on 2026-08-31.

| Item | Value |
| --- | --- |
| Board outline | 1.260 in × 2.602 in (32.00 mm × 66.10 mm) |
| Outline extents | X 19.95–51.95 mm, Y 19.95–86.05 mm |
| Copper layers | 4 — F.Cu, In1.Cu, In2.Cu, B.Cu |
| Pack terminals `J5A`/`J5B` | Y = 29.00 mm, F.Cu |
| Phase terminals `J4A`/`J4B`/`J4C` | Y = 80.50 mm, F.Cu |
| MCU `U1` (MSPM0G3518-Q1, LQFP-64) | Y = 78.50 mm, **B.Cu** |
| Secure element `U2` (OPTIGA Trust M) | Y = 81.50 mm, **B.Cu** |
| Probe pads `J1` | Y = 81.00 mm, **B.Cu** |
| Gate driver `U5` | Y = 60.00 mm, B.Cu |
| FET bridge `Q1`–`Q6` | Y = 53.50 and 66.00 mm, F.Cu |

### 2.1 Copper pour assignment — the fact that decides this variant

| Layer | Net | Extent |
| --- | --- | --- |
| F.Cu | `PH_A` | X 20.4–28.1, Y 55.2–85.5 mm |
| F.Cu | `PH_B` | X 28.6–43.0, Y 54.5–85.5 mm |
| F.Cu | `PH_C` | X 43.5–51.5, Y 55.2–85.5 mm |
| F.Cu | `VM` | X 20.4–51.5, **Y 20.5–60.3 mm** |
| F.Cu + B.Cu | `GND` | X 20.4–51.4, Y 20.5–85.5 mm |
| **In1.Cu** | **`GND`** | X 20.4–51.4, **Y 20.5–85.5 mm (full board)** |
| In2.Cu | `VM` | X 20.4–51.4, Y 20.5–60.5 mm |
| **In2.Cu** | **`GND`** | X 20.4–51.4, **Y 60.5–85.5 mm** |

At the terminal end (Y > 60.5 mm) **both inner layers are solid GND**. That
is the shield this variant needs, and it already exists. §4 is about
protecting it, not creating it.

### 2.2 There is no stackup — and that is the real gap

The board file contains **no `(stackup ...)` block**. It declares four copper
layers and `(thickness 1.6)` in its `general` block, which is KiCad's default
value, not a recorded design decision. Consequently the repository specifies
**none** of:

- dielectric height between F.Cu and In1.Cu, or between In2.Cu and B.Cu;
- copper weight on any layer (`conductor_sizing.py` prices 1/2/3 oz as
  options; nothing has been chosen);
- laminate relative permittivity or `Tg`;
- surface finish.

Every question in this document about separation, coupling and cost lands on
that gap. **Defining the stackup is task 15.2 and it gates the rest.**

### 2.3 Board width is locked

`docs/tools/isolation_envelope.py`, run 2026-08-31:

```text
creepage required          7.50 mm
isolated pin inset         1.43 mm from the board edge
widest non-isolated part  12.90 mm

MINIMUM BOARD WIDTH:
   12.90 + 2 x (7.5 + 1.43) + 2 x 0.55 = 31.86 mm
```

The 7.5 mm (0.295 in) figure is the ADM2582E/ADM2587E minimum external
clearance and creepage, Table 6 of [9] — a **verified** primary-source value.
The as-built 32.00 mm (1.260 in) clears the 31.86 mm (1.254 in) minimum by
0.14 mm (0.006 in). Width is not a free parameter in this variant.

---

## 3. Deriving the face assignment

Two assignments are possible. The pours in §2.1 decide it.

### 3.1 Phases must stay on F.Cu

All three phase pours are on F.Cu, spanning Y 55.2–85.5 mm — they already
reach the terminal end, and `J4A`/`J4B`/`J4C` at Y = 80.50 mm already sit
directly on them. `conductor_sizing.py`'s standing conclusion is that a
terminal must sit on its own pour or the connecting gap must itself be pour;
a 0.118 in (3.0 mm) track across that gap costs more power than all six FETs'
conduction loss combined (§7).

Moving the phases to B.Cu would take three 50 A terminals off their pour
layer and force a via field through both inner GND planes — perforating the
shield in exactly the window where it is needed. **Rejected.**

### 3.2 Therefore the pack moves to B.Cu

`J5A`/`J5B` move to B.Cu at the terminal end, opposite the phase pads.

- `GND` (VBATT−) is trivial: B.Cu already carries a GND pour there.
- `VM` (VBATT+) is the real work. The VM pour stops at Y 60.3 mm (F.Cu) and
  Y 60.5 mm (In2.Cu). VM must be carried roughly 1.18 in (30 mm) further to
  reach the B.Cu pad at Y = 90.50 mm, on a face where GND currently pours.
  B.Cu at the terminal end must be re-partitioned into a VM region and a GND
  region. **Not done** — `J5A` (VM) is deliberately left unconnected rather
  than bridged by a track, because a 3.0 mm track across that span costs more
  than all six FETs' conduction loss combined (§7). `J5B` (GND) is also
  unconnected, cut off from the B.Cu pour by the relocated outer-layer rule
  area — the same defect `TODO.md` 12.5.an measures on the parent. Both are
  the 12.5.ae sign-off, inherited unresolved.

### 3.3 What has to move — corrected 2026-08-31

**The partition originally proposed here is dead. Do not implement it.** It
moved `U1`/`U2`/`J1` to the logic end to free the terminal end. `U1`'s
courtyard measures **13.45 mm**, not the 12.90 mm §2.3's envelope calculation
assumed, so with `U1` at the logic end `isolation_envelope.py` returns:

```text
13.45 + 2 x (7.5 + 1.43) + 2 x 0.55 = 32.41 mm minimum board width
```

against an actual 32.00 mm — a **0.41 mm failure** against the [9] Table 6
creepage, which is verified and not negotiable. §11 open item 3 anticipated
exactly this, and §2.3's rule applies: *this variant needs a different
partition, not a wider board.*

**The partition actually built** leaves the logic cluster alone and buys
length at the terminal end instead. `isolation_envelope.py` prices width
against length at 2.7× here, so length is the cheap dimension.

| Item | Baseline | Variant as built |
| --- | --- | --- |
| Board outline | 32.00 × 66.10 mm | **32.00 × 76.10 mm** (+15.1 % area) |
| `J4A`/`J4B`/`J4C` phases | F.Cu, y 80.50 | F.Cu, **y 90.50** (still on their pours) |
| `J5A`/`J5B` pack | F.Cu, y 29.00 | **B.Cu, y 90.50** (opposite the phases) |
| `U1` / `U2` / `J1` | B.Cu, y ≈ 76–86 | **unchanged** |
| MCU → gate-driver run | ≈18.5 mm | **unchanged** |
| Current-sense returns | — | **unchanged** |
| `FID3` / `FID6` | y 83.65 | y 93.65 (move with the band) |
| Phase pours, FETs, `U5` | — | **unchanged** |

Because the logic cluster never moves, the two regressions §8.1 previously
listed — the lengthened gate-drive run and the lengthened current-sense
returns — **do not occur**. Applied by
`builds/6s/50A/CAN_485_faraday_sameend/kicad/tools/make_same_end_egress.py`.

## 4. The shield between front and back copper

This section answers the direct question: *what shielding can or should be
put between the front and back copper?*

### 4.1 The shield already exists

Per §2.1, at the terminal end (Y > 60.5 mm) **In1.Cu is solid GND and In2.Cu
is solid GND**. Two grounded planes lie between the phase pads on F.Cu and
the pack pads on B.Cu. Nothing needs to be added. A grounded plane between
two conductors does not attenuate their mutual field — it **terminates** it:
field lines from the phase pad end on the plane instead of continuing to the
pack pad. The residual is aperture and edge coupling, not bulk coupling.

**So the correct answer to "what shielding should go between the faces" is:
the shielding you already have, kept intact.** The work is protective, not
additive.

### 4.2 It is currently broken — this is the headline finding

The board carries an unnamed rule area:

```text
bbox      x 20.75..51.15 mm,  y 76.50..86.55 mm
layers    "F.Cu" "B.Cu" "In1.Cu" "In2.Cu"
keepout   (tracks allowed) (vias allowed) (pads allowed)
          (copperpour not_allowed) (footprints allowed)
```

It spans **all four copper layers** and forbids copper pour on every one of
them, across X 20.75–51.15 mm of a 19.95–51.95 mm outline — essentially the
full width — for Y 76.50–86.55 mm.

That is the exact window where the two terminal groups would face each other.
**As the board stands, the inner GND planes are cut away precisely where this
variant needs them to shield.** The rule area's evident purpose — keeping
pour off the outer-layer phase terminals — is fully served by scoping it to
F.Cu and B.Cu. Extending it to In1.Cu and In2.Cu buys nothing and removes the
shield.

**Fix:** restrict the rule area to the outer layers and let In1.Cu and In2.Cu
pour solid through the terminal window. This costs nothing and is the single
highest-value change in the whole variant.

### 4.3 Keep phase via transitions out of the window

A via through the inner planes needs an antipad — a hole in the shield. The
phase pads sit on their F.Cu pours and need no layer change, so no phase via
*has* to enter the terminal window. Make that a placement rule: **no phase or
VM via inside X 20.75–51.15, Y 76.50–86.55 mm**, so the shield stays
unperforated where the pads overlap.

### 4.4 Stitch the two planes into one cage

Tie In1.Cu and In2.Cu together with a GND via fence around the terminal
window perimeter so they behave as a single enclosure rather than two
independent sheets.

Stitch pitch is chosen against the highest frequency of interest. In a
laminate of relative permittivity `εr`, the wavelength is
`λ = c / (f · √εr)`. Taking `εr = 4.3` (a **nominal FR-4 value — this
repository has verified no permittivity for its laminate**, so this is marked
`UNVERIFIED — needs primary source (see TODO.md)`), `√4.3 = 2.074`:

| Frequency | λ in laminate | λ/20 stitch pitch |
| --- | --- | --- |
| 100 MHz | 56.9 in (1447 mm) | 2.83 in (72 mm) |
| 500 MHz | 11.4 in (289 mm) | 0.57 in (14 mm) |
| 1 GHz | 5.70 in (145 mm) | 0.28 in (7.2 mm) |

A 0.28 in (7.2 mm) pitch covers to 1 GHz. On a 1.260 in (32.00 mm) wide
window that is roughly five vias per side — trivially achievable. **Stitching
is not the hard part of this variant.** The λ/20 criterion is a common
engineering rule of thumb, not a standards requirement; no standard is cited
for it because none has been read in this repository.

### 4.5 What this shield is *not*

The `Faraday` EMI-hardening tier already carries a candidate board-level
shielding can, the Würth WE-SHC 3671375 [19], sized to cover the gate-drive
and switching-node area. That is a **surface** shield against radiated
emissions from the top of the board. It does not sit between the faces and
does not do this job. The two are complementary, not alternatives — do not
let one be quoted as satisfying the other.

---

## 5. Can the substrate be thickened to improve separation?

It can be thickened, but it is close to the wrong lever, for two reasons.

### 5.1 Thickening scales the wrong term, linearly

Face-to-face pad coupling is a parallel-plate capacitance,
`C = ε₀ · εr · A / h`. With `ε₀ = 8.854 × 10⁻¹² F/m`, `εr = 4.3`
(UNVERIFIED nominal, §4.4), and a pack pad of 7.0 mm diameter
(`A = π · 3.5² = 38.5 mm²`):

| Total thickness `h` | `C` face-to-face, **unshielded** |
| --- | --- |
| 0.063 in (1.6 mm) | 0.92 pF |
| 0.094 in (2.4 mm) | 0.61 pF |
| 0.126 in (3.2 mm) | 0.46 pF |

Doubling the laminate thickness halves the capacitance — one factor of two,
bought with a doubled board thickness. A grounded plane in between removes
the direct path altogether. **The plane is worth far more than the thickness,
and the plane is already paid for.**

### 5.2 The coupling that actually dominates is not face-to-face

The phase pours on F.Cu total at most 1.43 in² (922 mm²) — sum of the three
bounding boxes in §2.1; actual fill is less. Their capacitance to the In1.Cu
GND plane, at dielectric height `h₁`:

| `h₁` (F.Cu → In1.Cu) | `C` phase pours → GND plane |
| --- | --- |
| 0.004 in (0.10 mm) | 351 pF |
| 0.008 in (0.20 mm) | 176 pF |
| 0.014 in (0.36 mm) | 97 pF |
| 0.020 in (0.51 mm) | 69 pF |

At a typical 0.008 in (0.20 mm) prepreg that is **176 pF — roughly 190× the
0.92 pF face-to-face figure.** Displacement current follows `I = C · dV/dt`,
so this is the dominant common-mode injection path on the board, and it is
governed by a dielectric height the stackup has never specified (§2.2).

*Arithmetic illustration only:* at an edge rate of 1 V/ns, 176 pF passes
176 mA while 0.92 pF passes 0.92 mA. **The 1 V/ns figure is not a design
value** — the actual edge rate is set by the DRV8353S `IDRIVE` setting and
the gate resistors, neither of which is specified in this repository. Marked
`UNVERIFIED — needs primary source (see TODO.md)`. The ratio, not the
absolute number, is the point.

### 5.3 Thickening has its own costs

- **Z-height in the pocket.** Thickness is the one dimension a blind cavity
  most directly constrains. Going 0.063 → 0.126 in (1.6 → 3.2 mm) doubles the
  board's contribution to the pocket depth budget.
- **Via aspect ratio.** A 0.3 mm drill gives 5.3:1 at 1.6 mm, 8.0:1 at
  2.4 mm, 10.7:1 at 3.2 mm. Where a fab's plating limit sits is a vendor
  question, not a repository fact — see task 15.9.
- **Thermal.** A thicker laminate raises through-board thermal resistance on
  a design already dissipating 10.5 W in the FETs alone (§7).

**Recommendation: keep 0.063 in (1.6 mm) nominal, and spend the effort on
§4.2 instead.** If the pocket permits and a quote shows it is cheap, a modest
increase to 0.079 in (2.0 mm) is harmless — but it should be justified by
mechanical stiffness or connector retention, not by inter-face separation.

---

## 6. Would a fifth layer be needed?

**No — and five is not the right question.**

### 6.1 Not needed for shielding

Two solid GND planes already lie between the faces at the terminal end
(§2.1). A fifth plane adds nothing that In1.Cu and In2.Cu, poured solid and
stitched, do not already provide.

### 6.2 Five is not a normal fabrication count

Rigid FR-4 multilayers are laminated from double-sided cores bonded with
prepreg, so copper counts come in even numbers. A five-copper-layer order is
normally built as six with one layer unused, and priced as six. The practical
choice is therefore **4 versus 6**. This is stated as general fabrication
practice; **it must be confirmed with the chosen fab** (task 15.9) rather
than treated as a repository fact.

### 6.3 If six layers are ever justified, it will be for copper, not shielding

The genuine argument for six is cross-section, not isolation. This board
carries 50 A, and `conductor_sizing.py` (§7) shows 1 oz copper on the phase
pours alone dissipates 13.33 W — more than the six FETs' 10.5 W conduction
loss. Extra layers give extra parallel pour area. That is a real trade, but
it belongs to the copper-weight decision in task 15.2 and should be settled
by comparing **6 layers at 1 oz against 4 layers at 2 oz**, which are
different points on a cost curve, not by the shielding question.

---

## 7. Copper sizing

`docs/tools/conductor_sizing.py`, run 2026-08-31. Its own header states it is
a derivation from material constants and **not** an IPC-2152 result — that
distinction is preserved here.

Phase pour, 0.295 in × 0.866 in (7.5 mm × 22.0 mm), at 50 A:

| Copper weight | R (mΩ) | Drop (mV) | W per phase | W all three |
| --- | --- | --- | --- | --- |
| 1 oz | 1.778 | 88.9 | 4.44 | 13.33 |
| 2 oz | 0.889 | 44.4 | 2.22 | 6.67 |
| 3 oz | 0.593 | 29.6 | 1.48 | 4.44 |

The six Toshiba TPHR8504PL FETs [49] dissipate 6 × 1.75 W = 10.5 W of
conduction loss at this current. At 1 oz the phase pours alone exceed that —
the standing argument for 2 oz minimum on this board.

Pour-edge-to-terminal gap, 0.591 in (15 mm) in the baseline, at 2 oz:

| Gap fill width | R (mΩ) | W all three |
| --- | --- | --- |
| 0.118 in (3.0 mm) | 1.515 | 11.36 |
| 0.197 in (5.0 mm) | 0.909 | 6.82 |
| 0.295 in (7.5 mm) | 0.606 | 4.55 |

**Variant-specific consequence.** The phase side is unchanged, so its gap is
unchanged. The pack side creates a *new* gap that does not exist today: VM
must reach a B.Cu pad at Y ≈ 80 mm from a pour that currently stops at
Y ≈ 60.4 mm (§3.2). That run must be pour on B.Cu, not track — the table
above is the reason. Re-run the tool against the new geometry before drawing
copper (task 15.5).

---

## 8. Risks this variant creates

**Single-end egress deletes the physical separation between the pack harness
and the phase harness that the split-end baseline got for free.** Inside the
board the inner planes handle it (§4). Outside the board they do not: both
groups leave the pocket in one bundle, coupled along their whole run.

1. A common-mode choke on the pack input becomes **mandatory** for this
   variant where it is optional in the baseline. No part selected — task 15.7.
2. Build instructions must specify harness dress: phases as a twisted
   triplet, pack pair twisted, stated minimum bundle separation.
3. Conducted-emissions pre-compliance (`TODO.md` §7.3) must be run on *this*
   variant. The baseline result does not transfer.

**No claim is made about how much margin is lost.** That requires
measurement; inventing a figure would violate `AGENTS.md` §1.3.

### 8.1 Second-order consequences

| Consequence | Effect | Handled in |
| --- | --- | --- |
| Board grows 66.10 → 76.10 mm | +15.1 % area; length is the cheap dimension at the 2.7x rate isolation_envelope.py prices | §3.3 |
| `U1`/`U2`/`J1` stay put | **No regression** — the gate-drive and current-sense lengthening the dead partition would have caused does not occur | §3.3 |
| VM must reach B.Cu at the terminal end | New 50 A pour region on a face that is currently all GND | 15.5 |
| VM pour on B.Cu under the phase pours on F.Cu | Acceptable **only** if §4.2 is fixed first; otherwise unshielded | 15.3 |
| Five terminals concentrated at one end | Wires are a heat path out of the board; the gradient concentrates | 15.8 |
| Rule area must be re-scoped and split | New DRC rules, each needing a negative control | 15.3, 15.6 |

---

## 9. Alternatives considered and rejected

### 9.1 Thicken the laminate instead of fixing the shield

Rejected — §5. One factor of two, bought with doubled thickness, against a
grounded plane that removes the path entirely and is already in the stackup.

### 9.2 Same end, both groups on the outer faces, split onto the two long edges

Rejected on arithmetic, and superseded by the owner's 2026-08-31 decision.
Five terminals in one row need 2 × 7.0 mm + 3 × 5.0 mm = 29.0 mm of pad on a
32.00 mm edge, leaving 0.020 in (0.50 mm) per gap once four inter-pad gaps
and two edge margins are taken — not dressable with 6 mm² (≈10 AWG)
conductor, its solder fillet and its strain relief. Widening the board to
suit is priced at 3.0× by
`docs/solutions/architecture-patterns/isolation-geometry-sets-board-aspect.md`.

### 9.3 Phases on B.Cu, pack on F.Cu

Rejected — §3.1. Takes three 50 A terminals off their pour layer and forces a
via field through both inner planes, perforating the shield exactly where it
is needed.

### 9.4 Six layers for isolation

Rejected — §6. Six layers may eventually be justified for copper
cross-section, but not for inter-face shielding, which two existing planes
already provide.

---

## 10. Work breakdown

Mirrored into `TODO.md` §15. Sequencing: 15.1 → 15.2 → 15.3 → 15.4 → 15.5 →
15.6 → 15.7 → 15.8 → 15.9.

**15.1 — Instantiate the build tree.** *(done for the matrix half)* The
**Wire Egress** axis is in `docs/decision-matrix.xlsx` and
`docs/decision-matrix.json` as of 2026-08-31, values `Opposite-end` (default)
and `Same-end, opposite faces`, added by
`docs/tools/add_wire_egress_sheet.py`. Remaining: add the axis to the root
`README.md` build-options list, and instantiate
`builds/6s/50A/CAN_485_faraday_sameend/` per
`docs/solutions/architecture-patterns/esc-build-instantiation-workflow.md`.

**15.2 — Define the stackup. Gates everything downstream.** The board has
none (§2.2). Specify layer count, per-layer copper weight, every dielectric
height, laminate and `εr`, and surface finish, and write them into the
`.kicad_pcb` stackup block. Settle 4 layers at 2 oz against 6 at 1 oz (§6.3).
*Done when:* the stackup block exists and no value in it is "TBD".

**15.3 — Re-scope the terminal-end rule area. Highest value, lowest cost.**
Restrict the X 20.75–51.15, Y 76.50–86.55 mm rule area to F.Cu and B.Cu so
In1.Cu and In2.Cu pour solid through the terminal window (§4.2). Add the
placement rule barring phase and VM vias from that window (§4.3).
*Done when:* both inner planes show continuous fill across the window in the
filled-polygon data, not merely an edited rule area.

**15.4 — ~~Re-place `U1`, `U2`, `J1` to the logic end.~~ CLOSED 2026-08-31 —
not done, and must not be.** `U1` is 13.45 mm wide; at the logic end
`isolation_envelope.py` demands 32.41 mm against an actual 32.00 mm. Replaced
by the length-extension partition in §3.3, which leaves all three parts where
they are.

**15.5 — Extend VM to a B.Cu pad at the terminal end.** Re-partition B.Cu
Y > 60.5 mm into VM and GND regions; place `J5A`/`J5B`. Re-run
`conductor_sizing.py` for the new pack-side gap and apply its conclusion —
pour, not track (§7). *Done when:* the gap has a stated width, dissipation
and copper weight, with no "TBD".

**15.6 — Stitch In1.Cu to In2.Cu around the terminal window** at a pitch
justified against a stated highest frequency of interest (§4.4). Every new
DRC rule gets a **negative control** before it is trusted: this repo has
already had a full day of DRC runs quoted as evidence while the rules
producing that silence had never executed, hiding 79 real violations
(`CLAUDE-MEMORY.md`, *kicad-dru-silent-failure*). Keep every `(condition …)`
on one line — a multi-line condition silently invalidates the entire
`.kicad_dru` with exit 0 — and verify clause order, which is not commutative.
*Done when:* each rule has been *seen* to fire on a deliberately violating
scratch board, with the control procedure written beside it.

**15.7 — Common-mode choke on the pack input.** New for this variant (§8).
Select, size against pack current and switching fundamental, cite in
`REFERENCES.md` per `AGENTS.md` §2. *Done when:* insertion loss at the
switching fundamental is quoted from the part's own datasheet, not estimated.

**15.8 — Thermal re-run** over the new placement (§8.1). *Done when:*
junction temperatures for `Q1`–`Q6`, `U5`, `U1` are quoted at a stated
ambient, with no "TBD".

**15.9 — Obtain a fabrication quote** covering: 4 vs 6 layers; 1 oz vs 2 oz
outer and inner; 1.6 vs 2.0 vs 3.2 mm thickness; and the maximum via aspect
ratio accepted at each thickness (§5.3, §6.2). **No price appears anywhere in
this repository until it comes from a vendor quotation** — `AGENTS.md` §1.3.
*Done when:* a dated quote is recorded and the §5/§6 recommendations are
either confirmed or revised against it.

**15.10 — Conducted-emissions pre-compliance for this variant.** Add it and
its harness dress to the `TODO.md` §7.3 test plan (§8). *Done when:* the test
plan names this variant and its harness dress.

---

## 11. Open items

| # | Item | Blocking? |
| --- | --- | --- |
| 1 | Stackup undefined — no dielectric height, copper weight or `εr` anywhere (§2.2) | **Yes** — gates 15.3–15.9 |
| 2 | Rule area cuts the inner planes in the terminal window (§4.2) | **Yes** — the variant does not work until fixed |
| 3 | ~~Does `U1` become the widest non-isolated part?~~ **RESOLVED 2026-08-31: yes, 13.45 mm, and it invalidated the original partition (§3.3). Superseded by the length-extension partition.** | closed |
| 4 | Connector selection, inherited from `TODO.md` §12.4.l | **Yes** for layout |
| 5 | Laminate `εr` — nominal 4.3 used, none verified (§4.4, §5) | No — ratios hold regardless |
| 6 | Switching edge rate unspecified — `IDRIVE` and gate resistors not set (§5.2) | No — but 15.7 needs it |
| 7 | Fabrication cost structure — no quote obtained (15.9) | No |
| 8 | Bulk input capacitance still generic in the baseline BOM | No |

---

## 12. References used

Cited per `AGENTS.md` §1.2 against `REFERENCES.md`:

- **[9]** Analog Devices ADM2582E/ADM2587E data sheet, Rev. H — p. 5,
  "Insulation and Safety-Related Specifications," Table 6: 7.5 mm minimum
  external clearance and creepage. Used in §2.3 and 15.4. **Verified**
  (local copy `docs/datasheets/analog-devices-adm2582e-adm2587e-datasheet.pdf`).
- **[19]** Würth Elektronik WE-SHC 3671375 shielding cabinet — candidate for
  the `Faraday` EMI tier. Referenced in §4.5 to distinguish a surface shield
  from the inter-face shield this variant needs. Candidate status unchanged.
- **[49]** Toshiba TPHR8504PL MOSFET. Used in §7 for the 6 × 1.75 W
  conduction-loss figure.

Deliberately **not** cited, because no primary copy exists in this repository
and `AGENTS.md` §1.3 forbids asserting it:

- IPC-2221 Table 6-1 conductor spacing. See `REFERENCES.md`, "Pending
  Verification — IPC-2152 and IPC-2221".
- Any laminate permittivity, fabrication cost, fab via-aspect-ratio limit, or
  switching edge rate. All marked `UNVERIFIED` at the point of use.
- The λ/20 stitch-pitch criterion (§4.4) — a common engineering rule of
  thumb, presented as such; no standard has been read for it.

Repo tools whose output is quoted:

- `docs/tools/isolation_envelope.py` — §2.3, run 2026-08-31.
- `docs/tools/conductor_sizing.py` — §7, run 2026-08-31.
- `docs/tools/add_wire_egress_sheet.py` — 15.1, run 2026-08-31.

Prior learnings applied:

- `docs/solutions/architecture-patterns/isolation-geometry-sets-board-aspect.md`
  — §2.3, §9.2.
- `docs/solutions/architecture-patterns/esc-build-instantiation-workflow.md`
  — 15.1.
- `CLAUDE-MEMORY.md`, *kicad-dru-silent-failure* — 15.6.

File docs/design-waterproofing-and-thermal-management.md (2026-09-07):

# Design Decision: Waterproofing a Faceted / Hinged ESC, Without Defeating Its Cooling Path

Status: DRAFT (authoring complete, several items open — see "Open Items")
Applies to: Form Factor = Faceted rigid-flex, and any variant with a hinged
or otherwise serviceable access cover. The Flat/single-PCB baseline is
covered only for contrast (see §1).
Governing rules: AGENTS.md §1–§3 — every technical claim that requires a
primary source is verified and added to REFERENCES.md; anything not yet
verified is marked `UNVERIFIED — needs primary source` per §3, not guessed.

Supersedes the placeholder reference in README.md ("Ingress & environmental
protection") and TODO.md §2.6, both of which pointed at
`docs/design-submersible-cooling.md` — a file that was never authored. This
document replaces that pointer and that name: "submersible" describes only
one of the two variants this decision produces (§5), and is the wrong frame
for the actual threat model on most builds (§2).

## 1. Why the industry-standard answer stops working here

For a single flat rigid PCB, the standard low-cost ESC waterproofing is heat
shrink tube: slide a tube over the populated board, shrink it down, and the
board's two flat faces plus its perimeter are covered in one operation, with
wire leads exiting through the tube ends (which then usually get their own
smaller boots or a bead of hot-melt). This works because a flat rectangular
board is topologically a cylinder's worth of surface — one tube, one shrink
pass, done.

Two things this repository's Faceted rigid-flex form factor breaks, and one
thing any hinged-access build breaks, regardless of board form factor:

1. **A faceted board is not a single flat plane.** `docs/tools/strip_width.py`
   exists precisely because this form factor is a board folded into chords of
   a curved bore (nacelle, boom, tube). A shrink tube conforms to a
   constant-radius surface; it does not conform to a polygon of flat facets
   with reflex fold lines between them without wrinkling, tenting away from
   the board at each fold, or splitting at the fold under shrink tension. The
   folds are exactly where a wrap-based seal is weakest and least inspectable.
2. **A folded board has re-entrant geometry a tube cannot reach uniformly.**
   Depending on fold angle, the inside of a fold is compressed while the
   outside is stretched; component height differences between panels (e.g. a
   shunt on one facet, a shorter passive on the neighboring one) create air
   gaps under the tube that are invisible until the board is opened again —
   which leads to point 3.
3. **A hinged access cover is a standing requirement for repeated service,
   and heat shrink (like potting, §4.3) is a one-shot process.** Serenity-UAV's
   nacelle ESC bays are explicitly hinged with flush access covers for
   service access (sibling repository, `Serenity-UAV` — see §6). Any
   waterproofing method that must be destroyed to inspect or replace the
   board is incompatible with a design that already committed to opening
   that bay again.

**Consequence:** waterproofing this board is not "pick a better tube." The
sealing boundary has to move from the board's own surface to the
bay/cover assembly that already exists for mechanical access — i.e., the
ESC becomes a component *inside* an enclosure, not its own enclosure. That
reframing is what the rest of this document works out, including the point
where it collides with the cooling analysis already done in the sibling
repository (§6).

## 2. What "splash or spray" actually requires — and what it doesn't

The README/TODO currently ask for one variant to cover "IP ratings up to
IP68 and NEMA equivalents up to NEMA 6P" in the same breath as "Faceted
rigid-flex." IEC 60529 [56] does not treat these as points on one ladder;
Table 3's own clause 6 note separates the **jet family** (numerals 5/6) from
the **immersion family** (numerals 7/8) — a product is rated for one, the
other, or both explicitly (e.g. "IPX6/IPX7"), never implied by the higher
number alone [56].

| Numeral | IEC 60529 [56] definition (Table 3) | Test | Threat it matches |
| --- | --- | --- | --- |
| IPX4 | "Water splashed against the enclosure from any direction shall have no harmful effects" | Clause 14.2.4 | Rotor wash, rain, road spray on a ground vehicle, rotor-downwash spray on an aircraft |
| IPX6 | "Water projected in powerful jets ... from any direction shall have no harmful effects" | Clause 14.2.6 | Pressure-washing, heavy following-sea spray |
| IPX7 | "Ingress of water in quantities causing harmful effects shall not be possible ... temporarily immersed ... under standardized conditions of pressure and time" | Clause 14.2.7 | A ground vehicle fording a stream crossing |
| IPX8 | As IPX7 but "conditions ... agreed between manufacturer and user ... more severe than for numeral 7" | Clause 14.2.8 | Sustained submersion (the stated USV/marine case) |

**The aircraft and most ground-vehicle nacelle/bay case described in this
task is IPX4–IPX6: splash and spray, not immersion.** That distinction
matters enormously for this design, because it is the difference between "the
enclosure can still breathe and be actively air-cooled" (IPX4/6 — water is
excluded from a boundary that air still crosses, §4) and "the enclosure is a
closed pressure vessel with no air exchange at all" (IPX7/8 — §5.2). Treating
every build as if it must hit IPX8 forecloses air-cooling on builds that never
needed to give it up.

**Design rule adopted here:** resolve Ingress Protection and Form Factor as
one joint axis in the decision matrix, the same way
`docs/solutions/architecture-patterns/esc-build-instantiation-workflow.md`
already requires for Motor × Shaft-Sensor. A "Faceted rigid-flex, hinged
access, IPX4–6" build and a "Flat, sealed, IPX7–8" build are two different
mechanical designs sharing a schematic, not one design with a rating dial.
§5 below makes that split explicit as two named variants.

## 3. The layered boundary: separate "keeps water out" from "keeps air moving"

The mistake this section exists to head off: treating the bay's hinged cover
as if gasketing it shut is the whole answer. A fully gasket-sealed bay is
airtight to the level the gasket achieves, which directly removes the
aspirated-cooling air path the sibling repository's thermal analysis found
to be the only cooling path that actually works for this geometry (§6). The
fix is to put the ingress boundary and the airflow boundary at *different*
places, each doing one job:

```text
 outside air/spray                                          duct interior
        |                                                          |
        v                                                          v
  [ baffled / labyrinth louvre, NOT gasketed ]  <-- IPX4/6 by GEOMETRY, not seal
        |
        v
  [ bay cavity — open to air, NOT a sealed volume ]
        |
        v
  [ conformally coated board, IPC-CC-830C [57] ]  <-- IPX4-equivalent AT THE BOARD
        |
        v
  [ drainage: low-point weep to outside, below the board ]
        |
        v
  [ wire egress: sealed gland / potted boot ]      <-- the one true gasketed joint
```

### 3.1 Board level — conformal coating, not a wrap

IPC-CC-830C [57] qualifies conformal coatings by chemistry family (Type AR
acrylic, ER epoxy, SR silicone, UR polyurethane, XY Parylene, UT ultra-thin,
SC styrene block co-polymer) and includes Flexibility (§3.5.5) and Thermal
Shock (§3.7.2) as qualification tests [57] — this is the property that
matters here: a coating has to survive the facet fold lines flexing (during
assembly, and on any variant where the "rigid-flex" is not fully rigidized
after forming) without cracking, which a dip-and-cure rigid coating on a flat
board is never asked to do. **Which coating type is selected, and its
qualified flex/thermal-shock performance, is `UNVERIFIED — needs primary
source`** (TODO §2.6) — [57]'s Table of Contents confirms the test exists;
the pass/fail numbers are on pages of the standard not held locally (see
[57]'s caveat).

This gets the board itself to roughly IPX4-equivalent protection (moisture,
condensation, incidental splash reaching the board through the vent path)
without touching serviceability — a coated board un-hinges, gets inspected,
and re-installs exactly as an uncoated one would; nothing about coating is a
one-shot process the way potting is.

### 3.2 Enclosure level — baffle the vent, don't gasket it

An IPX4 test sprays water "from any direction" [56]; it does not force water
through a right-angle turn against its own momentum and gravity. The louvre
already exists in the sibling repository's nacelle cover for the aspirated
cooling path (`tools/nacelle_esc_thermal.py`'s `ESC_LOUVRE_N/W/L` and the FOD
screen sweep, §6) — the fix here is geometric, not material: offset the
louvre's outer opening from its inner (bay-side) opening by a baffle rib, so
a straight line from outside to the board interior does not exist. This is
the same principle NEMA 3R enclosures and automotive engine-bay louvres use
to breathe while shedding driving rain; it is a judgment call recorded as
such (AGENTS.md §4), not a cited numeric standard, because no primary source
in this repository's catalog gives a baffle-geometry IPX4 pass criterion —
the criterion is the IEC 60529 [56] test itself, applied to the finished
geometry, not derived analytically here.

**The FOD mesh already in `tools/nacelle_esc_thermal.py`'s `SCREENS` table
does not by itself buy splash resistance.** Its apertures (0.4–1.2 mm) are
sized against particle ingress, and a woven screen at that aperture does not
exclude liquid water — water at that pore scale is not held back by surface
tension the way it is in an ePTFE membrane (§3.3). Do not treat "has a FOD
screen" as "is splash-rated" — they are two different filters passing through
the same opening, and only the baffle geometry (this section) or a membrane
(§3.3) does the water job.

### 3.3 Pressure equalization, not cooling flow

A gasketed joint anywhere in the design (the wire-egress gland, §3.4, or a
hinge seal if the cover itself is gasketed on the sealed/immersion variant,
§5.2) will pressure-cycle with altitude and with the ESC's own thermal
cycling. A joint that is pushed outward on the way up and pulled inward on
the way down draws water in past a marginal seal on the down-stroke even
when the seal excludes it on a static soak test. GORE Protective Vents [58]
and similar ePTFE-membrane vents exist to equalize that pressure through a
membrane that "allows air to pass through while preventing the ingress of
liquids and particles" [58] — add one wherever a gasketed volume exists on
this design (i.e., on the §5.2 sealed variant; the §5.1 vented variant has no
sealed volume to equalize).

**This is not a cooling path.** [58]'s own highest-airflow model is quoted at
7600 ml/min at 70 mbar — call it under 0.01 g/s of air — against the
aspirated circuit's mass flow of tens of grams per second at throttle in the
sibling repository's analysis (`aspirated_flow()` in
`tools/nacelle_esc_thermal.py`, §6). A pressure-equalization vent is sized to
prevent seal damage over an altitude/thermal cycle, not to carry heat. Do not
size one against the thermal budget; size it against the enclosed volume and
expected pressure-altitude excursion (`UNVERIFIED — needs primary source`,
no sizing method for this is catalogued yet — TODO §2.6).

### 3.4 Wire egress — the actual weak point

Every option above still has to get phase and pack conductors, and any sense
lines, out of the bay. This is the one joint on the §5.1 (vented) variant
that legitimately needs a gasketed seal, because it is the one boundary
crossing that is not also an airflow path. No connector series is currently
selected in this repository with a stated IP rating (`grep` of README.md and
TODO.md turns up none), so this is tracked as an open item rather than a
part number invented here: select a connector or cable-gland series with a
manufacturer-stated IP rating at the *mated, installed* condition (not the
unmated pin), and hold its datasheet locally per AGENTS.md §1.3 before it
enters a BOM. Until then, a drip loop — routing the cable to a local low
point below the gland before it rises to the connector, standard practice in
marine and aviation wiring so that water running down the cable drips off
before it reaches the seal — is a no-cost, zero-BOM-impact mitigation worth
building into the harness routing regardless of which connector is chosen.

### 3.5 Drainage — assume the boundary above will someday be beaten

Every layer above reduces the rate of ingress; none of them, on the vented
variant, claims to be absolute (that is what distinguishes IPX4/6 from
IPX7/8, §2). The bay floor should have a low point below the board with a
path to the outside — even a single small weep hole works, since the goal is
to let the small amount of water that gets past the baffle (§3.2) leave
before it pools against the coated board (§3.1) rather than to keep the bay
bone-dry. This costs nothing but placement discipline in the CF-PETG bay
geometry and should be checked the same way `nacelle_esc_thermal.py` checks
the cooling path: as a real geometric flow path, not "a hole exists."

## 4. Thermal and waterproofing are not separable on this geometry

This is the section that makes the whole document necessary rather than a
restatement of "use a gasket": the sibling repository's
`tools/nacelle_esc_thermal.py` already established, for the closely related
Serenity-UAV nacelle ESC bay, that:

- A sealed bay relying on conduction through CF-PETG walls fails at every
  plausible thermal conductivity in the material's plausible band (`Option A`
  in that tool) — the pod's own plastic is not a working heat path.
- An aluminum conduction path to the stator sleeve heat sink works, at a
  measured mass cost (`Option B`), but requires the sink to be a fixed metal
  part reachable by a solid conduction chain — i.e., no hinge or air gap in
  that path.
- The only path with margin at forced-air hover current is **aspirated
  cooling**: air drawn from the duct's inter-stage suction, through the bay,
  carrying the board's heat out as it goes (`Option C`).

Option C is only available on a bay that stays *open to airflow*. That is
the vented variant this document has been building toward in §3: keep the
ingress boundary at the board (coating) and the baffle (geometry), and keep
the airflow boundary open, rather than collapsing both boundaries onto one
gasketed lid. **A gasketed, gore-vented sealed bay — the obvious-looking
"just make it an IP67 box" answer — would reproduce Option A's failure by
removing the only cooling path that passes**, on any build dissipating
ESC-class power without an independent metal path to a heat sink.

## 5. Two variants, not one dial

Per the joint-axis rule in §2, this document's answer to "how do we
waterproof and cool a faceted, hinged ESC" is: it depends which of two
mechanical designs the build actually needs, and both should exist as named
Form-Factor × Ingress combinations in `docs/decision-matrix.xlsx` rather than
one "IP rating" field applied uniformly.

### 5.1 Splash/spray, air-cooled (target IPX4–IPX6)

- Faceted rigid-flex board, IPC-CC-830C [57]-qualified flexible coating.
- Bay stays open to air; access cover hinges normally, no compression gasket
  on the hinge or the vent.
- Baffled/labyrinth louvre geometry at every opening (§3.2); FOD mesh stays,
  understood as a particle filter, not a water seal.
- Gasketed wire-egress gland only (§3.4), with a drip loop.
- Bay-floor drainage to a low-point weep (§3.5).
- Cooling: the sibling repository's aspirated circuit (`Option C`), unchanged
  by anything in this document — this variant is compatible with that
  analysis by construction, since nothing here closes the air path.
- This is the variant that matches the Serenity-UAV nacelle case as
  described (§6): an aircraft ESC subject to rotor-wash spray, not
  submersion.

### 5.2 Sealed / immersion (target IPX7–IPX8)

- Flat or unfolded board (a folded/faceted board complicates a compression
  gasket's sealing plane — this variant is not the faceted one), potted or
  fully gasketed enclosure, no air exchange with the outside.
- Pressure-equalization vent [58] required (§3.3) to protect the seal over
  thermal/altitude cycling, sized against volume and excursion, not thermal
  load.
- Cooling: no aspirated path is available (there is no outside air to draw
  on), so this variant must use the sibling repository's `Option B`-style
  answer — a solid metal conduction path from the board to an external heat
  sink or the vehicle's own structure — sized the same way `Option B` was
  sized there (thermal resistance chain, `k`-swept where the conductor's
  conductivity is not a verified figure). This is the USV/marine submersible
  case the README's "up to IP68" line was actually describing.
- Serviceability is reduced by design (potting) or preserved only if the
  seal is a re-usable compression gasket rather than a pour; which of those
  two this variant uses is `UNVERIFIED — needs primary source` / an open
  design decision (TODO §2.6), since it trades service access against seal
  margin and no requirement in this repository currently forces one answer.

## 6. Relationship to the Serenity-UAV nacelle analysis

`tools/nacelle_esc_thermal.py` in the sibling repository **Serenity-UAV**
(not part of this repository; referenced descriptively, not by in-repo path)
performs the thermal-only half of this problem for that project's specific
nacelle geometry: two Open-Secure-ESC boards per nacelle, in bays cut into a
CF-PETG pod's annulus, with hinged access covers and louvred FOD screens.
Its conclusions (Options A/B/C, and the duct-pressure argument for why a
"bleed" circuit flows backwards while an "aspirated" one works) are treated
here as an already-verified input, not re-derived — this document's
contribution is the ingress-protection layer that has to coexist with that
cooling design (§4) without undoing it, plus the general (not
Serenity-UAV-specific) two-variant framework of §5 for any other host using
a faceted or hinged Open-Secure-ESC build.

## Open Items (tracked in TODO.md §2.6)

- [ ] Select a conformal coating meeting IPC-CC-830C [57] with its
      Flexibility (§3.5.5) and Thermal Shock (§3.7.2) qualification data
      obtained from a primary source (vendor datasheet naming IPC-CC-830C
      compliance), not assumed from the coating "type" alone.
- [ ] Select a wire-egress connector/gland series with a manufacturer-stated
      IP rating at the mated condition; hold its datasheet locally.
- [ ] Size the pressure-equalization vent (§3.3) against bay free volume and
      the design altitude/thermal excursion — no sizing method is catalogued
      yet.
- [ ] Verify whether IEC 60529 Amendments 1/2 changed the IPX4/6/7/8 clause
      numbers or definitions relative to the 2001 text held locally [56].
- [ ] Confirm, for the §5.2 sealed variant, whether service access is
      required (compression gasket) or may be sacrificed (potting) — this is
      a requirements decision, not an engineering one, and is currently open.
- [ ] If a rigid-flex bend radius or flex-endurance standard is ever needed
      for the Faceted form factor's fold lines, note that
      `docs/tools/strip_width.py` already flags that none is catalogued in
      REFERENCES.md — do not fabricate one; add it via the normal citation
      workflow (AGENTS.md §2) when actually needed.

## Related

- `AGENTS.md` §1.3 (no fabrication), §3 (marking unverified content), §4
  (design-decision rationale)
- `REFERENCES.md` [56]–[58]
- `docs/tools/strip_width.py` — the faceted board's own geometry constraint,
  and its existing "no flex/rigid-flex standard catalogued" flag
- `docs/solutions/architecture-patterns/esc-build-instantiation-workflow.md`
  — the joint-axis-resolution pattern this document follows for Form Factor
  × Ingress Protection
- `TODO.md` §2.6 — the open items this document feeds
- Serenity-UAV (sibling repository) `tools/nacelle_esc_thermal.py` — the
  cooling-path analysis this document's §4 builds on without re-deriving

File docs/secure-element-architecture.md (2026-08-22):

# Secure Element Architecture — OPTIGA™ Trust M + MSPM0G3518-Q1 AESADV

**Status:** design record, 2026-08-10; **revised 2026-08-22** to describe the
project MCU that is actually on the schematic (see `TODO.md` §13).
**Applies to:** `builds/6s/50A/CAN_485_faraday` (schematic `U1` =
**MSPM0G3518-Q1**, `U2` = OPTIGA™ Trust M).
**Governing rules:** `AGENTS.md` §1–§5. Every claim below is either traced to a
primary source in `REFERENCES.md` or explicitly marked `UNVERIFIED` / `OPEN`.

This document is the "full split and security-monitor budget" referenced by
`symbols/specs/OPTIGA_TRUST_M.json`, `symbols/specs/MSPM0G3518_Q1_PM.json`, and
the corresponding `.kicad_sym` Description properties.

> **2026-08-22 revision note.** The 2026-08-10 version of this document
> described the NXP S32K144's CSEc module throughout. The MCU swap decided
> 2026-08-10 ([44], `TODO.md` §13) replaced `U1` with the TI MSPM0G3518-Q1
> **before** this document was updated to match — confirmed by reading the
> schematic directly: `U1`'s `lib_id` is `MSPM0G3518_Q1_PM:MSPM0G3518_Q1_PM`
> (`open_secure_esc_6s_50a_can485_faraday.kicad_sch` line 4489), and the
> `VCORE`/`NRST`/`SE_I2C_SCL`/`SE_I2C_SDA`/`SE_RST` nets and the dedicated
> 470 nF `C_VCORE` cap are present and wired (schematic notes at lines 949,
> 953, 1041–1049, 3147, 3329, 3924, 3952, 3959–3973, 4022–4036, 5267, 6064).
> This pass rewrites every CSEc-specific claim below for the MSPM0's AESADV
> engine and Keystore, closing `TODO.md` 13.1.e. The S32K144 material is kept
> in §9 as history, not deleted, per this repo's convention of not erasing
> superseded design record. **The Trust M's own justification (§1) does not
> change** — the MSPM0's AES engine is still symmetric-only, so the Trust M is
> still the only source of asymmetric identity and key agreement in this
> design.

---

## 1. Why a secure element, and why not a TPM

The ESC needs an **independent hardware root of trust**: a key store whose
private keys cannot be extracted by compromising the application MCU, and which
can prove the board's identity to a peer.

Three options were considered across this repo's history:

| Option | Verdict | Reason |
| --- | --- | --- |
| Discrete TPM 2.0 (Infineon SLB9672, [2]) | **Dropped 2026-08-03** | Full TPM 2.0 stack (TSS, PCRs, attestation state machine) is far more machinery than an ESC needs, and it consumed an LPSPI channel. See `TODO.md` 4.1 / 11.3. |
| On-chip MCU AES engine alone (S32K144 CSEc [31], superseded; MSPM0G3518-Q1 AESADV [44], current) | **Insufficient alone** | Symmetric-only on both parts considered. See §2. |
| **Secure element (OPTIGA™ Trust M, [45])** | **Selected** | Supplies exactly the asymmetric layer neither MCU option has, over I²C, in a 3 mm × 3 mm (0.118 in × 0.118 in) package. |

**The Trust M is not a reinstatement of the SLB9672.** It is a different device
class. A TPM is a platform-integrity module built around PCRs and attestation; a
secure element is a key vault with a crypto engine. The Trust M reuses only the
schematic designator `U2` that the SLB9672 vacated. It is also **unaffected by
the S32K144 → MSPM0G3518-Q1 MCU swap**: its own datasheet, pin count, and
justification are independent of which MCU it talks to over I²C.

### 1.1 The gap the MCU's own AES engine cannot close

The MSPM0G3518-Q1's `AESADV` peripheral provides an AES-128/256 accelerator
with GCM support and a hardware-backed `Keystore` for up to four AES keys
([44] p.1 "Features"; §8.20/§8.21 exist as device sections per [44] p.5 TOC).
The wider MSPM0 platform security architecture — Customer Secure Code (CSC),
Boot Image Manager (BIM), the Keystore's access model, and a hardware
monotonic counter — is described in [40] (SLAAE29A). Per [40] p.2 Table 1-1:
"Only CSC can configure keys into Keystore and the main application can
configure the crypto engine (AES) to use one of the stored keys but can never
access any stored keys." [40] also states plainly that **SHA2-256 and ECDSA
P-256 exist only as software libraries on MSPM0** — "Only supported via
software in MSPM0 devices" (p.2 Table 1-1) — with **no hardware acceleration**
for either, and **no certificate-handling command** anywhere in the cited
material.

That means the MSPM0's on-chip crypto — like the S32K144's CSEc before it —
structurally cannot cheaply perform:

- public-key **device authentication** with hardware-accelerated signing
  (proving identity to a party that holds no shared secret);
- **key agreement** with a peer it has never met;
- any form of certificate validation.

A firmware-only ECDSA-P256/SHA-256 software stack is *possible* on the MSPM0
(the SDK libraries exist per [40]), but it runs on the Cortex-M0+ core with no
hardware acceleration, has no protection against key extraction beyond
ordinary flash-read protection, and cannot replicate the Trust M's
fab-provisioned, non-exportable private key or its certificate store. This
repo's design does not attempt to substitute software ECDSA for the Trust M;
the finding survives the MCU swap unchanged.

**The Trust M closes this gap on both MCUs equally** — nothing about the
asymmetric-layer requirement is MCU-specific.

---

## 2. Division of labour

| Concern | Device | Rationale |
| --- | --- | --- |
| Device identity, ECDSA signature over a fab-provisioned private key | **Trust M** | Private key never leaves the SE; provisioned at Infineon's fab with the public key signed by a customer CA ([45] p.11 §2 Note). |
| Certificate storage / trust anchors | **Trust M** | 4 × X.509 slots, 3 × trust-anchor slots ([45] p.10 Fig. 1). |
| Ephemeral session-key agreement (ECDHE + KDF) | **Trust M** | ECC NIST P-256/384/521, Brainpool r1, HKDF SHA-256/384/512, TLS v1.2 PRF ([45] pp. 8–9 Table 4). |
| **Per-frame message authentication (hot path)** | **MSPM0 `AESADV`** | AES-128/256 CMAC-class authentication in hardware on the MCU, no I²C round trip to the Trust M, no security-monitor throttle. |
| Session-key custody during flight | **MSPM0 `Keystore`** — **mechanism `OPEN`, see C-08** | Up to 4 AES key slots ([44] p.1); how a *runtime-negotiated* ECDHE session key gets loaded into a Keystore slot that [40] states only CSC can configure is not yet designed. See C-08 below. |

The one-sentence version: **the Trust M decides *who you are* once; the MCU's
own AES engine proves *this frame is from you* continuously** — the same
division of labour as before the swap, on a different MCU.

**What changed from the S32K144 design, concretely:**

- The S32K144's CSEc had an explicit `RAM_KEY` volatile slot documented for
  exactly this purpose ([31] Table 36-75) — load a session key at runtime,
  outside the flash-resident key catalog, no CSC-equivalent gatekeeper. The
  MSPM0G3518-Q1's Keystore, per the only primary-source description found
  ([40] p.2 Table 1-1), is described as CSC-configured only. Whether the
  `AESADV` engine can also consume a key supplied directly from application
  RAM/registers (bypassing Keystore, the way CSEc's `RAM_KEY` bypassed its own
  flash catalog) is **not confirmed from the cited sources** — see C-08.
- The key budget dropped from CSEc's 20 non-volatile slots
  (`SECRET_KEY`, `MASTER_ECU_KEY`, `BOOT_MAC_KEY`, `KEY_01`–`KEY_17` — [31]
  Table 36-75) plus 1 volatile `RAM_KEY`, to the MSPM0's 4 Keystore slots
  ([44] p.1). See §4 C-08 / `TODO.md` 13.1.f for the headroom analysis.

---

## 3. The security-monitor budget — the constraint that shapes the design

This is the single most important integration constraint, and it is the reason
the hot path *cannot* live on the secure element. **This section is entirely
about the Trust M and is unaffected by the MCU swap** — the numbers below come
from [45], not from whichever MCU is on the other end of the I²C bus.

The Trust M contains a security monitor that throttles operations it classes as
**protected** ([45] p.28 §7.1–§7.2, read from the local verified copy):

> `t_max` is set to 5 seconds (± 5%) … One protected operation … per `t_max`
> period. In other words it must not allow more than one out of the protected
> operations per `t_max` period (worst case).

The protected events are ([45] p.28 Table 19):

| Event | Triggered by |
| --- | --- |
| Decryption failure | Failed integrity check during protected update |
| Key derivation | `DeriveKey` on a **persistent** data object |
| **Private key use** | Any internal service using an SE-hosted private key **except** temporary keys from session context |
| Secret key use | Any use of an SE-hosted symmetric key, except session-context temporaries |
| Suspect system behaviour | Internal consistency check failure |

**Design consequences, in order of importance:**

1. **Device authentication is a boot-time event, not a runtime one.** An ECDSA
   signature with the fab-provisioned identity key is "private key use" — one
   per 5 s, worst case. Authenticating per frame, per command, or even per
   second is impossible by construction.
2. **The motor-control hot path must never call the Trust M.** A 6s/50 A ESC
   updating at kHz rates would exceed the budget by three orders of magnitude
   and be throttled into failure. The MCU's own AES engine carries the hot
   path; this is a hard architectural boundary, not a preference, and it holds
   for the MSPM0G3518-Q1 exactly as it held for the S32K144.
3. **Session-context keys are exempt.** The exemption for "temporary keys from
   the session context" is what makes an ECDHE handshake practical: the
   ephemeral key operations inside an established session context are not
   counted as protected operations. The *identity* key use that bootstraps the
   session is.
4. **Re-keying is expensive.** Because re-authentication costs a ≥5 s budget
   slot, sessions are necessarily long-lived, which raises the value of the
   session key and argues for deriving successive MCU-side keys from a KDF
   ladder rather than repeatedly returning to the SE.

---

## 4. Cryptographic assessment

Findings from a cryptographic review of the combined design. Severity is
engineering judgment; the underlying facts are cited.

### C-01 — AES-128 ceiling on the authenticated hot path (RESOLVED 2026-08-10 by the MCU swap)

**Original finding (S32K144 design):** the Trust M offers AES up to 256 bit and
ECC to P-521 ([45] pp. 8–9 Table 4), but none of that raised the strength of
the hot path, because the hot path ran on CSEc, which is AES-128 only ([31] RM
Rev. 14 §5.2.2, printed p. 97: "AES-128, CBC, ECB, CMAC"; "All cryptographic
functions are processed by an AES-128 engine", printed p. 880).

**Resolution:** the MSPM0G3518-Q1 was selected specifically to retire this
ceiling — "AES-128/**256** accelerator with support for GCM" ([44] p.1
"Features") — because, in the repo owner's own words (`docs/HANDOFF-mcu-swap-
s32k144-to-mspm0g3518.md` §1), *"I'd rather have AES-256 than be limited to
128."* The hot path can now run at AES-256 if firmware configures it to.

**Kept for the record, because the underlying observation still matters:**
128-bit symmetric strength was and remains adequate well beyond 2030 under
current NIST guidance — the original finding was informational/accepted, not a
defect, and the swap is a strength upgrade, not a fix for a broken design.

### C-02 — No post-quantum algorithm anywhere in the chain; the identity key cannot be rotated to one (Medium, one-way door — unaffected by the MCU swap)

Neither the MSPM0's `AESADV`/software crypto nor the Trust M offers ML-KEM
(FIPS 203), ML-DSA (FIPS 204), or SLH-DSA (FIPS 205). The Trust M's crypto set
is classical ECC/RSA ([45] pp. 8–9 Table 4); [40] describes only classical
software ECDSA-P256/SHA-256 on the MSPM0 side.

The aggravating factor is **immutability**: the identity private key and its
X.509 certificate are generated and provisioned **at Infineon's fab** ([45] p.11
§2 Note). A field firmware update cannot migrate that key to a PQC algorithm,
and this is true regardless of which MCU sits next to the Trust M.
Crypto-agility for device identity therefore requires a **hardware** change.

Mitigating: session keys are ephemeral (ECDHE), so "harvest-now-decrypt-later"
exposure is bounded to identity and attestation, not to bulk flight data — and
the bus is not confidential in the first place (see O-02). This is filed as a
known, accepted limitation of the device class, not a blocker.

### C-03 — Authentication alone does not stop replay; a freshness value is required (High, OPEN — unaffected by the MCU swap)

AES CMAC-class authentication authenticates *content*, not *recency*. Without a
freshness input, a recorded valid frame replays as a valid frame — which on a
motor-control bus means a recorded throttle command can be re-injected. This
holds regardless of which MCU computes the MAC.

The Trust M's 4 monotonic counters ([45] p.10 Fig. 1) are boot/session-scale
objects and are far too slow to serve as a per-frame freshness source (each use
risks the §3 budget). The MSPM0 has its own hardware monotonic counter ([40]
p.37 §4.7) intended for firmware anti-rollback, not per-frame freshness at
control-loop rates; using it per-frame has not been evaluated and is not
assumed to be appropriate.

**Required:** a monotonically increasing freshness value inside the
MCU-authenticated payload, maintained by firmware and reset only on
re-authentication. **This is a firmware design obligation and is not yet
specified.** Tracked in `TODO.md` §12.3.

### C-04 — CAN-FD frame budget forces MAC truncation (Medium, design decision required — API details now `UNVERIFIED` for the new MCU)

CAN-FD carries at most 64 byte of payload — the S32K144's FlexCAN module
declared "Zero to sixty four bytes data length" ([31], S32K1xx Series
Reference Manual Rev. 14, §55.2.2 "Features", printed p. 1802), and [44] p.1
lists CAN-FD support for the MSPM0G3518-Q1 without contradicting the 64-byte
CAN-FD payload ceiling, which is a protocol-level (ISO 11898-1, [6]) limit, not
a silicon-specific one. The governing ISO text [6] is cited for the protocol
itself but is paywalled and its clause content is `UNVERIFIED` in
`REFERENCES.md`.

A full 128-bit CMAC is 16 byte — 25% of a maximum-size frame, and it does not
fit at all alongside useful data in a classic 8-byte frame.

**API-level change from the MCU swap:** CSEc exposed truncation directly —
`MAC = TRUNCATE(CMAC_KEY,KEY_ID(MESSAGE, MESSAGE_LENGTH), MAC_LENGTH)` ([31] RM
Rev. 14, printed p. 894). Whether the MSPM0's `AESADV` CMAC/GCM path exposes an
equivalent truncated-tag option, or whether firmware must truncate the full tag
itself post-computation, is **`UNVERIFIED — needs primary source`**: [44]'s
p.1 feature summary and [40]'s architecture overview do not go to that level
of API detail, and the AESADV chapter body ([44] §8.20) has not been read this
pass. Tracked as a new item, `TODO.md` 13.1.i.

The security math is unchanged either way: truncating to 32 bit gives a 2⁻³²
per-attempt forgery probability. On a bus an attacker can hammer, that is
**not** sufficient on its own — it must be paired with a verification-failure
rate limit or lockout, or the effective security degrades to the attacker's
attempt rate. **The chosen `MAC_LENGTH` and the failure-handling policy are not
yet decided.** Tracked in `TODO.md` §12.3.
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

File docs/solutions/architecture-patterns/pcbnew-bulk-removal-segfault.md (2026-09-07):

---
date: 2026-09-05
problem_type: architecture_pattern
category: architecture-patterns
module: builds
component: pcbnew_scripting
severity: high
applies_when:
  - "A pcbnew script bulk-removes zones, tracks, or drawings from a live BOARD"
  - "A script calls board.GetDrawings() / board.Zones() / board.Tracks() more than once in one process"
  - "A pcbnew script exits 139 (SIGSEGV) after its last print statement, with no Python traceback body"
  - "board.Save() appears to have worked but the shell command still reports failure"
tags:
  - pcbnew
  - kicad
  - swig
  - segfault
  - scripting
  - placement
related_components:
  - docs/tools/facet_placement.py
  - CLAUDE-MEMORY.md
---

# pcbnew bulk item removal segfaults at process exit unless `thisown` is cleared
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

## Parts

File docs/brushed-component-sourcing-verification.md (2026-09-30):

# Active Components Compliance & Origin Analysis

To ensure compliance with defense procurement or supply chain security standards (such as **NDAA Section 889**, **DFARS 252.225-7007**, or **ITAR / EAR compliance**), silicon shall not originate from restricted entity lists or covered regions (primarily China and Russia).
Below is the verification breakdown for the active components across all tiers:

## **1\. Core Microcontroller & Security Root of Trust**

| Component | Function | Vendor | Wafer Fab / Primary Diffusion | Assembly & Test | Compliance Status |
| :---- | :---- | :---- | :---- | :---- | :---- |
| **MSPM0G3518-Q1** | Primary Microcontroller | Texas Instruments (USA) | USA / Japan | Malaysia / Taiwan / Thailand | **Compliant** |
| **OPTIGA™ Trust M V3** | Security Element / Common Criteria | Infineon (Germany) | Dresden, Germany / Villach, Austria | Malaysia / Philippines | **Compliant** |

## **2\. Tier 1: Integrated H-Bridge ICs (2S–6S / 10A–20A)**

| Component | Function | Vendor | Wafer Fab / Primary Diffusion | Assembly & Test | Compliance Status |
| :---- | :---- | :---- | :---- | :---- | :---- |
| **DRV8873-Q1 / DRV8874** | Integrated H-Bridge Driver | Texas Instruments (USA) | USA (Dallas, TX / Sherman, TX) | Taiwan / Malaysia | **Compliant** |

## **3\. Tier 2 & Tier 3: Gate Drivers & Controller Interfaces**

| Component | Function | Vendor | Wafer Fab / Primary Diffusion | Assembly & Test | Compliance Status / Notes |
| :---- | :---- | :---- | :---- | :---- | :---- |
| **DRV8706-Q1** | Smart Gate Driver (Up to 37V) | Texas Instruments (USA) | USA | Taiwan / Philippines | **Compliant** |
| **DRV8718S-Q1** | Multi-Channel Gate Driver (High-V) | Texas Instruments (USA) | USA | Taiwan / Malaysia | **Compliant** |
| **LTC7010** | High-Side / Half-Bridge Driver | Analog Devices / LTC (USA) | USA (Camas, WA / Milpitas, CA) | Malaysia / Philippines | **Compliant** |
| **L6387E** | Gate Driver (*Optional Spec*) | STMicroelectronics (EU) | Agrate, Italy / Crolles, France | Shenzhen, China | ⚠️ **Use Caution / Replace** *(Backend assembly occurs in China).* |

**Substitution Recommendation:** Replace the ST L6387E with the **Texas Instruments DRV8706-Q1** or **Analog Devices LTC7004 / LTC7010** across all builds to keep gate drivers 100% compliant with US/EU supply chain directives.

## **4\. Power MOSFET Silicon (Discrete Power Stage)**

| Component | Specs & Package | Vendor | Wafer Fab / Primary Diffusion | Assembly & Test | Compliance Status |
| :---- | :---- | :---- | :---- | :---- | :---- |
| **IPT012N08N5** | 80V, 1.2mΩ (HSOF-8) | Infineon (Germany) | Villach, Austria / Dresden, Germany | Melaka, Malaysia / Regensburg, Germany | **Compliant** |
| **IPT015N10N5** | 100V, 1.5mΩ (HSOF-8) | Infineon (Germany) | Villach, Austria / Dresden, Germany | Melaka, Malaysia / Regensburg, Germany | **Compliant** |
| **SUM70042E** | 100V, 4.2mΩ (TO-263) | Vishay Siliconix (USA) | USA (Santa Clara, CA) | Migdal HaEmek, Israel / Taiwan | **Compliant** |
| **IPB072N15N3G** | 150V, 7.2mΩ (TO-263) | Infineon (Germany) | Villach, Austria | Melaka, Malaysia | **Compliant** |

## **5\. Nacelle-tilt build (6S / 10 A / brushed) — parts added 2026-09-17**

Rows added for `builds/6s/10A/BRUSHED_CAN_485_isolation/`. Vendor comes from each datasheet's imprint (`REFERENCES.md` tags);
fab and assembly sites are **not stated in any datasheet** and are carried
as `UNVERIFIED — needs primary source (see TODO.md 18.4)` until a vendor
country-of-origin statement or a distributor COO document is on file.
Nothing in this table may be read as a compliance verdict until then.

| Component | Function | Vendor | Wafer Fab / Primary Diffusion | Assembly & Test | Compliance Status |
| :---- | :---- | :---- | :---- | :---- | :---- |
| **DRV8874-Q1** [63] | Tier-1 integrated brushed H-bridge (orderable; [62] is the non-Q1 twin) | Texas Instruments (USA) | see §2 row for DRV8873-Q1 / DRV8874 — same family; site not stated in [63] | as §2 | **Pending** — UNVERIFIED — needs primary source (see TODO.md 18.4) |
| **TPS54560B** [65] | 6–7 V motor/solenoid rail buck, 4.5–60 V in, 5 A | Texas Instruments (USA) | not stated in [65] — UNVERIFIED — needs primary source (see TODO.md 18.4) | not stated in [65] — UNVERIFIED | **Pending** |
| **TPL7407L** [66] | Pin-brake solenoid low-side driver (2 channels paralleled), clamp to COM | Texas Instruments (USA) | not stated in [66] — UNVERIFIED — needs primary source (see TODO.md 18.4) | not stated in [66] — UNVERIFIED | **Pending** |
| **AEAT-8800-Q24** [64] | Remote worm-shaft absolute magnetic encoder (off-board, SPI/SSI) | Broadcom (imprint "Copyright © 2016–2017 by Broadcom"; HQ location not stated in [64]) | not stated in [64] — UNVERIFIED — needs primary source (see TODO.md 18.4) | not stated in [64] — UNVERIFIED | **Pending** |

## **Verification Summary & BOM Rules for Procurement**

> * **100% Compliant Core Architecture:** The TI MSPM0 MCU, OPTIGA Trust M V3 security chip, and the primary Infineon OptiMOS power MOSFETs originate entirely from fabs and packaging facilities in **the United States, Western Europe, Israel, Taiwan, Thailand, and Malaysia.**
> * **Gate Driver Standardization:** Standardize on TI's automotive driver suite (**DRV8706-Q1** and **DRV8718-Q1**) or Analog Devices drivers rather than generic European drivers (like ST's L6387E) to ensure that backend assembly remains outside of China.
> * **Traceability Requirement:** For OSHWA and government/industrial supply chain verification, require **Certificate of Origin (COO)** documents from authorized distributors (e.g., Arrow, Mouser, Digi-Key) for each batch reel prior to PCB assembly.

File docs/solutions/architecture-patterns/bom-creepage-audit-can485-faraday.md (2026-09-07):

---
date: 2026-09-06
problem_type: architecture_pattern
category: architecture-patterns
module: builds
component: board_geometry
severity: high
applies_when:
  - "Auditing a BOM for creepage/clearance reduction opportunities"
  - "Working voltage and current rating are both fixed and cannot be reduced"
  - "Trying to shrink a board carrying isolated CAN and/or RS-485 interfaces"
  - "Deciding between two isolator part variants that differ only in package"
tags:
  - isolation
  - creepage
  - bom-audit
  - can
  - rs-485
  - board-geometry
  - datasheet-verification
related_components:
  - REFERENCES.md
  - docs/tools/isolation_envelope.py
  - docs/solutions/architecture-patterns/isolation-geometry-sets-board-aspect.md
  - docs/solutions/architecture-patterns/smaller-package-does-not-shrink-creepage.md
  - builds/6s/50A/CAN_485_faraday
---

# BOM-wide creepage audit, with 50A/6S and working voltage held fixed

## Context

Two prior findings on this build established that (1) board width is set by
isolation creepage geometry, not placement luck
(`isolation-geometry-sets-board-aspect.md`), and (2) swapping an isolated
transceiver for a smaller-package part does not reduce the required creepage,
because creepage is set by the barrier's working-voltage/insulation class per
IEC 60664-1, not by package size or chip count
(`smaller-package-does-not-shrink-creepage.md`). This document is the
follow-on: with 50 A / 6S and the resulting working-voltage class both held
fixed as hard constraints (per the build's own protocol/battery requirements,
not a preference), what is left in the BOM and layout that genuinely reduces
creepage or board area — audited part by part, not guessed.

## Findings, ranked by verified impact

### 1. MCU package: PM (LQFP-64) → RHB (VQFN-32) — the largest lever found

`docs/tools/isolation_envelope.py`'s "widest non-isolated part" figure
(12.90 mm) is `U1`'s current PM package body/courtyard. TI's own MSPM0G3518-Q1
datasheet [44] lists an RHB (VQFN-32, 5×5 mm nominal body) package option for
the *identical part number* — same die, same AES-128/256 + keystore + TRNG.
Every signal this build's schematic assigns to specific PM pins was checked,
pad by pad, against RHB's Table 6-2 IOMUX options (RHB exposes only PA0–PA27,
no Port B/C at all) and a fully conflict-free assignment exists with 4 GPIOs
to spare — CAN0_TX/RX, UART0 TX/RX/RTS(RS-485 DE), SPI1 CS0/SCK/POCI/PICO
(gate driver), all three TIMA0 complementary PWM pairs, I2C1 SCL/SDA (secure
element), SWCLK/SWDIO, and all four ADC channels. Re-running
`isolation_envelope.py` with the RHB footprint:

```text
PM  (12.90 mm widest part):  needs 31.86 mm width to sit inboard of both isolated rows
RHB (~6.5 mm w/ courtyard):  needs 25.46 mm — closes 82% of the gap to a 24 mm target
```

This is the only change examined across this whole audit that reduces the
*non-isolated* side of the geometry rather than fighting the isolated side,
and it is a package-option change on a part already in the BOM, not a new
part number.

### 2. CAN transceiver variant: close the "left open" ADM3055E/ADM3057E decision — free 0.5 mm

REFERENCES.md [10]'s Table 2 "Timing Characteristics" is a single table
covering **both** ADM3055E and ADM3057E — 12 Mbps maximum data rate for
either, no per-variant split anywhere in it. The only differences are
package and UL rating:

| | Package | CLR/CRP | UL 1577 VISO | VIORM/VIOWM |
| --- | --- | --- | --- | --- |
| ADM3055E | RI-20-1 "increased creepage" | 8.3 mm | 5000 V rms | 595 Vpk / 420 Vrms |
| ADM3057E | RW-20 "wide body" | **7.8 mm** | 3750 V rms | 595 Vpk / 420 Vrms (identical) |

Since the two parts are timing-identical and carry the *same* reinforced
working-voltage rating, ADM3057E is strictly better for this board's purpose
unless something downstream specifically requires the higher UL proof
voltage. **The board's own PCB already has this resolved in practice**: `U3`
in `builds/6s/50A/CAN_485_faraday/kicad/*.kicad_pcb` is placed on footprint
`SOIC-20W_7.5x12.8mm_P1.27mm` — dimensionally the RW-20 (ADM3057E) package,
not RI-20-1. The schematic `Value`/`Description` fields and README still
carry the decision as "left open"; this should be closed to ADM3057E
explicitly (see REFERENCES.md [10] addendum, 2026-09-06) rather than left
ambiguous, and the KiCad footprint should be independently checked against
[10]'s own RW-20 land pattern (Outline Dimensions, p. 27) — that dimensional
check is not yet done and is tracked in TODO.md.

**This is a genuine 0.5 mm creepage reduction at zero functional cost.** It
is small next to item 1, but it costs nothing to take.

### 3. Consolidating CAN + RS-485 onto one shared isolation barrier — promising, NOT yet verified feasible

Today this board pays the creepage-zone overhead (pin inset + edge margin,
not just the raw creepage number) **twice** — once for `U3` (CAN) and once
for `U4` (RS-485) — even though both already sit on one shared island with
one keepout per the existing placement (`README.md` "bottom right... A
copper keepout removes every plane and pour from that band"). The
architectural question worth asking: could ONE multi-channel reinforced
isolator carry both interfaces' signals across a single barrier, with bare
(non-isolated) CAN and RS-485 transceivers living on its isolated side,
powered from its own integrated DC-DC — eliminating a second full component
footprint and its own inset/margin overhead, even though the per-barrier
creepage number itself would not shrink?

TI's ISOW7841 [61] was checked as a concrete candidate: quad-channel
reinforced digital isolator, integrated DC-DC (up to 650 mW, "eliminates the
need for a separate isolated power supply"), SOIC-16 body 10.30 × 7.50 mm,
>8 mm creepage/clearance at 1000 V rms working voltage. **It does not fit as
a drop-in**: CAN needs 2 channels (TX, RX) and this build's RS-485 uses 3
(TXD, RXD, DE/RE) — 5 total against ISOW7841's 4. Two ways to close that gap
exist, neither verified here:

- Tie DE and RE-bar into one shared direction-control line (a single
  transistor inverter on the isolated side recovers the second control
  signal) — brings RS-485 to 2 lines, CAN + RS-485 = 4, fits exactly.
- Select an automatic-direction-sensing RS-485 transceiver (no DE/RE pin at
  all) — same result, no inverter needed.

**Neither a specific automatic-direction RS-485 transceiver nor a verified
current budget (does 650 mW / the achievable output current actually cover a
bare CAN transceiver plus a bare RS-485 transceiver simultaneously at 16 Mbps
and 50 Ω bus loading?) has been checked against a primary datasheet.** There
is also an unrecorded functional-safety trade this repository has not made a
decision on: today a fault on the CAN bus and a fault on the RS-485 bus are
isolated from *each other*, not just from the MCU; merging both onto one
barrier removes that channel-to-channel separation. That is a real design
decision requiring its own justification under `AGENTS.md` §4, not an
incidental side effect to accept by default. **This item is recorded as a
direction worth a follow-up spike, not a recommendation to implement.**

### 4. PCB creepage-extending geometry (grooves/ribs/slots) — real technique, not yet usable here

Every isolator datasheet checked in this audit ([9], [10], [59], [60], [61])
carries the same footnote, verbatim in substance: "Techniques such as
inserting grooves, ribs, or both on a printed circuit board are used to help
increase these specifications." This is a real IEC 60664-1 provision — a
routed slot between two creepage domains lengthens the *surface path* a
tracking failure would have to follow, which can let a design meet a given
creepage figure over a shorter *straight-line* distance than an unbroken
board surface would need, in principle shrinking board width without
changing which parts are used at all.

**This repository does not yet catalog the actual IEC 60664-1 clause that
governs slot width/depth vs. credited creepage distance**, and every
datasheet's footnote stops at naming the technique, not quantifying it. Using
a groove without that clause would mean claiming a creepage credit that
cannot be traced to a verified source — exactly what `AGENTS.md` §1.3
prohibits. **Open item:** obtain and cite the specific IEC 60664-1 clause
(likely in its Annex on grooves/ribs) before this technique is applied to any
layout, and mark it `UNVERIFIED — needs primary source` until then.

### 5. Board edge margin (0.55 mm) — small, unverified, possibly fab-limited rather than safety-limited

`isolation_envelope.py`'s `EDGE_MARGIN_MM = 0.55` is not attributed to a
specific fab's design rules in this repository's citation trail — it reads
as a generic copper-to-board-edge allowance, not a creepage requirement
itself (the 7.5 mm+ creepage figures already account for the isolator's own
safety margin). If the actual fab house's minimum copper-to-edge clearance is
smaller than 0.55 mm, this could be tightened for a small (≤0.5 mm total,
both edges) width reduction. **Open item:** trace this figure to the
target fab's stated design rules before relying on it, per the same
`AGENTS.md` §1.3 discipline as everything else in this audit — it is not
large enough to change any conclusion above, but it should not be asserted
as a hard 0.55 mm floor without a source either.

### 6. Everything else in the BOM checked and found NOT to carry its own creepage boundary

For completeness, the rest of the BOM was checked for hidden isolation
crossings that would each demand their own creepage zone: the gate driver
(`U5`, DRV8353S) and its SPI bus to `U1` share the battery-negative ground
domain with the MCU — no isolation, no creepage boundary. The secure element
(`U2`, OPTIGA Trust M) is on the same non-isolated domain via I2C. The
current-sense amplifiers (`U6`–`U8`, INA240) and shunts are single-domain.
**Only `U3` (CAN) and `U4` (RS-485) carry an isolation barrier on this
board.** There is no third hidden creepage zone to find or consolidate.

## What This Means for "Rearrange for a Smaller Board"

The single most effective *rearrangement* already exists in this design and
should be preserved, not re-litigated: `U3` and `U4` already share one
isolated island with one keepout (`README.md`, "bottom right... A copper
keepout removes every plane and pour from that band"), so the two barriers
are not each paying a separate keepout today. The rearrangement lever that
remains open is the one `isolation_envelope.py` already names as the
alternative to an inboard fit: put the non-isolated control section (`U1`,
`U2`, decoupling) on a **different facet** of the Faceted rigid-flex form
factor than the isolated pair, paying board *length* across a fold rather
than trying to win *width* at the isolation boundary — which is what the
Faceted form factor exists to do, and item 1 above (the RHB MCU package)
makes that facet's own footprint dramatically smaller regardless of which
strategy is chosen.

## When to Apply

- Any BOM audit where working voltage/insulation class cannot move (fixed by
  protocol, battery chemistry, or a certification requirement already made).
- Before proposing a "smaller isolator" swap — check `smaller-package-does-
  not-shrink-creepage.md` first; this document is the audit that follows once
  that avenue is closed off.
- Before treating two isolated interfaces as requiring two independent
  creepage zones by default — check whether they can share one island first
  (already done here) and whether they could share one barrier (item 3,
  still open).

## Related

- `docs/solutions/architecture-patterns/isolation-geometry-sets-board-aspect.md`
- `docs/solutions/architecture-patterns/smaller-package-does-not-shrink-creepage.md`
- `docs/tools/isolation_envelope.py`
- `REFERENCES.md` [9], [10] (with 2026-09-06 addendum), [44], [59], [60], [61]
- `builds/6s/50A/CAN_485_faraday/README.md` — current placement description
- `TODO.md` — tracks the open items in findings 3, 4, and 5

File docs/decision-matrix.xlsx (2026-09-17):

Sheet: Legend
Open-Secure-ESC — Design Option Decision Matrix
Generated 2026-08-02. Governed by AGENTS.md / REFERENCES.md / TODO.md in the repo. This workbook is a derived view — the repo files are the source of truth.
Purpose | One sheet per README.md build axis (Voltage, Amperage, Protocol, Control, EMI Hardening). Each row is one build option; columns show the workflow steps and BOM component(s) that option requires, with REFERENCES.md citation tags and a verification status.
Status legend
Verified (local PDF) | A local, directly-verified PDF copy exists in docs/datasheets/ and page/section citations were read from it (e.g. [1] MSPM0G3507, [2] SLB9672).
Candidate (unverified) | A real part/standard was identified and cross-corroborated via 2+ independent secondary sources (distributor listings, search-indexed excerpts), but this session's live-fetch tool (WebFetch) returned HTTP 403 for every domain tried, so no primary PDF was opened directly and no local copy exists yet. Not yet selected in a bill of materials.
Open / unresolved | No specific part or authoritative spec has been sourced yet; tracked as an open TODO.md item.
No part needed | The MCU's own native peripheral (or a layout/practice-only technique) covers this option — no additional BOM line.
Methodology caveat
Every entry marked "Candidate (unverified)" in this workbook corresponds to REFERENCES.md tags [12]-[23], added 2026-08-02. This session's WebFetch tool returned HTTP 403 for every domain attempted -- including a neutral non-vendor control URL used as a sanity check -- so specs for those parts are corroborated via secondary sources only, not read directly from a primary datasheet PDF. Per AGENTS.md, these must not be treated as settled citations until a working fetch path or manual PDF download resolves them (see TODO.md 1.10). Do not remove this caveat until that verification pass happens.
Sheets in this workbook
Voltage | Battery voltage tiers (2S-12S): pack nominal/max/min voltage and component-derating workflow.
Amperage | Motor current tiers (10A-120A): power MOSFET, gate driver, and current-sensing BOM per tier.
Protocol | The 11 communication protocol options: MCU-native vs. added-transceiver BOM and workflow.
Control | The 3 control-loop topologies: feedback-sensing approach and firmware workflow.
EMI Hardening | The 4 EMI tiers: governing standard(s) and BOM part (or layout-only) per tier.
Motor | Brushed vs brushless: bridge topology, switch-position count, gate-driver part, shunt count. Changes the power stage, not just a setting.
Shaft Sensor | Sensorless / Hall / quadrature encoder / resolver: MCU pin budget, connector, and any added IC.
Amended 2026-08-16: added the Motor and Shaft Sensor axis sheets. Cells reading 'TBD -- requires primary-source verification' are genuinely unsourced, not placeholders to be filled in from memory (AGENTS.md Sec.1.3).
Holding Brake | None / low-side solenoid driver: actuation, fail-state (the safety property), MCU pins, driver part, connector, firmware sequencing.
Amended 2026-09-17: added the Holding Brake axis; resolved the Motor sheet's Brushed (DC) row (DRV8874-Q1 [63]); added the magnetic-absolute shaft-sensor row (AEAT-8800-Q24 [64]).

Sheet: Voltage
Voltage Tier Decision Matrix
Build axis: Voltage (2S / 4S / 6S / 8S / 12S)
Per-cell assumption (candidate cell)
Cell part | Molicel INR-21700-P42A [14]
Nominal V / cell | 3.6
Max (full charge) V / cell | 4.2
Min (cutoff) V / cell | 2.5
Tier | Series Cells | Nominal Pack V | Max Pack V | Min Pack V | Workflow / Derating Steps | BOM Components | REFERENCES.md Tags | Status
2S | 2 |  |  |  | Derate FET [20] VDS and bulk-capacitor voltage rating against Max Pack V with margin (~2x recommended); verify DRV8353S [21] VM range (9-75V) spans Max Pack V; select input protection/reverse-polarity FET rated ≥ Max Pack V. | Bulk input capacitor (V rating ≥ Max Pack V); shares FET [20] / gate driver [21] from Amperage sheet | [14], [20], [21] | Candidate (unverified)
4S | 4 |  |  |  | Derate FET [20] VDS and bulk-capacitor voltage rating against Max Pack V with margin (~2x recommended); verify DRV8353S [21] VM range (9-75V) spans Max Pack V; select input protection/reverse-polarity FET rated ≥ Max Pack V. | Bulk input capacitor (V rating ≥ Max Pack V); shares FET [20] / gate driver [21] from Amperage sheet | [14], [20], [21] | Candidate (unverified)
6S | 6 |  |  |  | Derate FET [20] VDS and bulk-capacitor voltage rating against Max Pack V with margin (~2x recommended); verify DRV8353S [21] VM range (9-75V) spans Max Pack V; select input protection/reverse-polarity FET rated ≥ Max Pack V. | Bulk input capacitor (V rating ≥ Max Pack V); shares FET [20] / gate driver [21] from Amperage sheet | [14], [20], [21] | Candidate (unverified)
8S | 8 |  |  |  | Derate FET [20] VDS and bulk-capacitor voltage rating against Max Pack V with margin (~2x recommended); verify DRV8353S [21] VM range (9-75V) spans Max Pack V; select input protection/reverse-polarity FET rated ≥ Max Pack V. | Bulk input capacitor (V rating ≥ Max Pack V); shares FET [20] / gate driver [21] from Amperage sheet | [14], [20], [21] | Candidate (unverified)
12S | 12 |  |  |  | Derate FET [20] VDS and bulk-capacitor voltage rating against Max Pack V with margin (~2x recommended); verify DRV8353S [21] VM range (9-75V) spans Max Pack V; select input protection/reverse-polarity FET rated ≥ Max Pack V. | Bulk input capacitor (V rating ≥ Max Pack V); shares FET [20] / gate driver [21] from Amperage sheet | [14], [20], [21] | Candidate (unverified)

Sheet: Amperage
Amperage Tier Decision Matrix
Build axis: Amperage (10A / 20A / 30A / 40A / 50A / 80A / 120A)
Tier (A) | FET Qty / Phase Leg | FET Part | FET Total Rated Capacity (A) | Margin (x) | Gate Driver Part | Shunt R (mΩ) | Shunt Drop (mV) | Shunt Power (W) | Shunt Qty Needed | Current-Sense Amp (Gain) | REFERENCES.md Tags | Status
10 | 1 | Infineon IRFB4110PBF [20] |  |  | TI DRV8353S [21] | 10.000 |  |  |  | TI INA240 [22], 20 or 50 V/V | [20], [21], [22], [23], [62], [63] | Candidate (unverified)
20 | 1 | Infineon IRFB4110PBF [20] |  |  | TI DRV8353S [21] | 5.000 |  |  |  | TI INA240 [22], 50 V/V | [20], [21], [22], [23] | Candidate (unverified)
30 | 1 | Infineon IRFB4110PBF [20] |  |  | TI DRV8353S [21] | 2.000 |  |  |  | TI INA240 [22], 100 V/V | [20], [21], [22], [23] | Candidate (unverified)
40 | 1 | Infineon IRFB4110PBF [20] |  |  | TI DRV8353S [21] | 1.500 |  |  |  | TI INA240 [22], 100 V/V | [20], [21], [22], [23] | Candidate (unverified)
50 | 1 | Infineon IRFB4110PBF [20] |  |  | TI DRV8353S [21] | 1.000 |  |  |  | TI INA240 [22], 200 V/V | [20], [21], [22], [23] | Candidate (unverified)
80 | 2 | Infineon IRFB4110PBF [20] |  |  | TI DRV8353S [21] | 0.500 |  |  |  | TI INA240 [22], 200 V/V | [20], [21], [22], [23] | Candidate (unverified)
120 | 3 | Infineon IRFB4110PBF [20] |  |  | TI DRV8353S [21] | 0.500 |  |  |  | TI INA240 [22], 200 V/V | [20], [21], [22], [23] | Candidate (unverified)
Shunt part: Vishay WSLP2512 [23] (3.0W package rating). "Shunt Qty Needed" = ROUNDUP(Shunt Power / 3W, 0); at 80A/120A this correctly computes 2x and 3x devices in parallel (7.2W / 3 tiers exceeds a single package's rating). FET parallel count and gate-driver reuse are a BOM-commonality choice (AGENTS.md §4 judgment call), not a datasheet requirement -- a smaller SO-8 FET would be leaner for the 10A-30A tiers if part-count commonality were not prioritized. -- BRUSHED BUILDS (2026-09-17): the FET Part, Gate Driver Part, Shunt and Current-Sense Amp columns of this sheet are brushless-shaped and are OVERRIDDEN by the Motor sheet's bridge row for a Brushed (DC) build (Tier 1: DRV8874-Q1 [63] integrated bridge, no shunt). This sheet still governs the copper and connector class for the tier.

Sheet: Motor
Motor Type Decision Matrix
Build axis: Motor (Brushed / Brushless)
Motor Type | Bridge Topology | Switch Positions | Gate Driver Part | Output Terminals | Shunt Qty | Commutation Requirement | REFERENCES.md Tags | Status
Brushless (BLDC / PMSM) | Three half-bridges (3-phase inverter) | 6 (3 high + 3 low) | TI DRV8353S, 3-phase smart gate driver, SPI variant [21] | 3 (PH_A / PH_B / PH_C) | 3 (one per phase, low-side) | Six-step trapezoidal or FOC; rotor position from the Shaft Sensor axis | [21] | Verified (local PDF)
Brushed (DC) | Single H-bridge | 4 (2 high + 2 low) | TI DRV8874-Q1 [63] integrated N-channel H-bridge (non-Q1 twin DRV8874 [62]): 4.5-37 V VM, 6 A peak, 100 mOhm typ per FET, PH/EN or PWM control, IPROPI current mirror 450 uA/A, VREF/ITRIP current regulation, UVLO/CPUV/OCP/TSD. Tier 1 (2S-6S, 10-20 A) per docs/OpenSecureESC-Brushed-Specifications.md Sec.1; every fault coasts the bridge ([63] Table 7). | 2 (M+ / M-) | 0 -- the driver's IPROPI current mirror replaces the shunt and current-sense amplifier of the brushless tiers ([63] Sec.7.3.3.1) | None -- direction and magnitude set by bridge polarity and duty cycle; no rotor position needed for basic operation | [62], [63] | Verified (local PDF)

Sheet: Shaft Sensor
Shaft Sensor Decision Matrix
Build axis: Shaft Sensor (None-sensorless / Hall / Quadrature encoder / Resolver)
Sensor Type | Rotor Position Source | MCU Pins Required | Additional BOM Component | Connector | Firmware Workflow Steps | REFERENCES.md Tags | Status
None (sensorless) | Back-EMF / observer computed from phase voltages and currents; same observer the Control sheet's closed-loop rows already use (TI SLAAE96A [13]) | 3 ADC (one per phase voltage divider). Reuses the current-sense ADC channels already allocated on the Amperage axis. | 3 resistor dividers (6 R) plus filter capacitors, one per phase. Generic passives, values sized against the pack voltage of the chosen Voltage tier. | None -- no sensor cable leaves the board | Implement the observer per [13]; handle open-loop startup ramp, since back-EMF is unusable near zero speed. | [13] | Candidate (unverified)
Hall effect (3-sensor, 120 deg) | Three digital Hall outputs giving six commutation states per electrical revolution | 3 digital in (interrupt-capable), plus a sensor supply rail | 3 pull-up resistors plus ESD protection on the cable entry. Sensor part: TI DRV5013 is carried from the Control sheet as a fallback candidate, at that sheet's existing status -- it has not been separately verified for this axis. | 5-pin (VCC, GND, HA, HB, HC) | Decode the 3-bit Hall state into a 6-step commutation table; derive speed from state-transition timing. | [1] | Open / unresolved
Quadrature encoder (incremental) | Two phase-quadrature channels A/B, plus optional once-per-rev index Z | 2 digital in, or 3 with index. Prefer a timer with a hardware quadrature decoder if the chosen MCU has one. | Pull-ups for an open-collector encoder, or a differential line receiver for RS-422 encoders -- TBD -- requires primary-source verification (AGENTS.md Sec.1.3) | 4-pin (VCC, GND, A, B) or 6-pin with Z and shield | Configure the hardware quadrature decoder; establish a zero reference from the index pulse or a homing routine. | - | Open / unresolved
Resolver | Ratiometric SIN/COS windings excited by an AC reference; absolute position within one electrical revolution | Depends on the converter: an SPI or parallel bus to a resolver-to-digital converter, plus an excitation output | Resolver-to-digital converter IC and an excitation amplifier -- TBD -- requires primary-source verification (AGENTS.md Sec.1.3). This is the only shaft-sensor option that adds a whole IC to the BOM. | 6-pin (EXC+, EXC-, SIN+, SIN-, COS+, COS-), shielded | Drive the excitation reference; read absolute angle from the converter; no startup ramp needed, unlike sensorless. | - | Open / unresolved
Magnetic absolute (SPI/SSI) | Single-turn absolute angle from an on-axis Hall sensor IC reading a diametric two-pole magnet on the shaft end; 10- to 16-bit absolute word over SSI/SPI, optional ABI/UVW/PWM outputs. Multi-turn position is accumulated in firmware. | 3 (SCLK, DO, NSL/CS) for SSI, 4 with DI for SPI; sensor supply 3.3 V. The sensor may sit off-board on a short cable. | Broadcom AEAT-8800-Q24 [64], QFN-24 5 x 5 mm, 3.3 V or 5 V operation, SSI 3-wire absolute output. Series resistors and ESD protection on each line per docs/design-speed-sensor-integration.md. | 6-pin keyed (3V3, GND, SCLK, DO, NSL, DI) with shield/drain optional | Read the absolute word each control tick; unwrap turns across the 0/full-scale boundary; home the multi-turn count from an outer absolute reference (a host sensor over the bus) at power-up; declare 'stationary' from this sensor, not from motor current. | [64] | Verified (local PDF)

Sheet: Holding Brake
Holding Brake Decision Matrix
Build axis: Holding Brake (None / Low-side solenoid driver, spring-applied)
Brake Option | Actuation | Fail-state | MCU Pins Required | Additional BOM Component | Connector | Firmware Workflow Steps | REFERENCES.md Tags | Status
None | No holding brake. The load is held by the motor's own drag, a self-locking transmission, or nothing. | Not applicable -- the build has no brake to fail. A non-self-locking transmission on a load that must hold unpowered may NOT select this row. | 0 | None | None | None | - | No part needed
Low-side solenoid driver, spring-applied | Spring-applied, power-released pin brake. A pull solenoid retracts the pin while its coil is energised; the spring engages the pin when the coil is released. The coil is switched on its low side. | De-energised = engaged. The driver input carries a pull-down so an MCU reset, brown-out or floating GPIO engages the brake without firmware; the coil's inductive kick is clamped; brake state (drive-pin readback) is published on the bus. Engage-on-fault: the motor driver's nFAULT is a brake-engage input for firmware. | 1 digital out (BRAKE_EN) plus 1 digital in or ADC for state readback; optionally 1 ADC for the coil supply rail so the pin is never dropped into a driven castellation. | TI TPL7407L [66]: 40 V 7-channel NMOS low-side array, 600 mA per channel (channels paralleled for the load), 1 MOhm input pull-down per channel, internal clamp diodes to COM. Return COM to the pack-side rail so the clamp sits above the coil supply and inside the COM range (8.5-40 V, [66] Sec.6.3). The solenoid itself is a host-side part outside this axis (Serenity-UAV item BRK-4); this row carries only the driver. | 2-pin (COIL+, COIL-) keyed header; polarity marked | Release only on an authenticated release command after the loop has unloaded the pin; sequence release -> move -> settle (encoder stationary) -> engage; engage on nFAULT, on bus loss after a timeout, and on coil-rail droop below the solenoid hold-in voltage; publish brake state every telemetry frame. | [66] | Verified (local PDF)
Note: A brake on the actuator shaft protects against loss of drive, not against a broken transmission downstream of it. The 'Fail-state' column is the safety property this axis exists to record -- a build that selects the solenoid row must reproduce every item in it, not just the part number. First instance: builds/6s/10A/BRUSHED_CAN_485_isolation/ (Serenity-UAV nacelle tilt).

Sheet: Protocol
Protocol Interface Decision Matrix
Build axis: Protocol (11 options)
Protocol | MCU Native Peripheral? | Additional BOM Component | Workflow Steps | REFERENCES.md Tags | Status
PWM | Yes -- TIMx advanced/general-purpose timers [1] §8.29 | None | Configure MCU timer capture/compare input; map duty-cycle/period per protocol variant. | [1] | No part needed
SBus | No native RX/TX invert (checked [1] p.67 §8.23, Table 8-15 -- no polarity-select feature listed) | External signal inverter (single-transistor or logic buffer) -- part not yet selected | Source Futaba SBus signaling spec (proprietary, no official spec located); build/verify external inversion circuit for the MCU's native UART RX; mark implementation UNVERIFIED per REFERENCES.md. | [1] | Open / unresolved
DBus | Same as SBus -- no native invert | Same external inverter approach as SBus -- part not yet selected | Same treatment as SBus: proprietary protocol, no official spec located; external inversion hardware needed. | [1] | Open / unresolved
UART | Yes -- UART0-3 [1] §8.23, p.67 | None (logic-level only) | Configure MCU UART peripheral (baud, parity, stop bits) per protocol variant. | [1] | No part needed
TTL | Yes -- shares UART peripheral [1] §8.23 | None (logic-level only) | Same as UART; TTL refers to the logic-level signaling, not a distinct peripheral. | [1] | No part needed
SPI | Yes -- two SPI peripherals [1] §8.25 | None | Configure MCU SPI peripheral (mode, clock rate up to 32 Mbit/s on one instance). | [1] | No part needed
RS-232 | No -- needs 3.3V-to-RS-232 level shifting | ADM3232E [12] (candidate; alt. considered: TI MAX3232) | Select RS-232 transceiver; verify ±15kV ESD and 3.3V-native supply match MCU rail; per [3]. | [1], [3], [12] | Candidate (unverified)
RS-485 | No -- needs isolated RS-485 transceiver | ADM2582E / ADM2587E [9] (candidate) | Select isolated RS-485 transceiver; verify ANSI/TIA/EIA-485-A-98 compliance and isolation voltage; per [4]. | [4], [9] | Candidate (unverified)
CAN2.0 | Yes -- CAN peripheral supports CAN2.0A/B [1] §8.26, p.68 | ADM3055E / ADM3057E [10] (isolated transceiver, candidate) | Configure MCU CAN peripheral for classic frames; select isolated CAN transceiver; per [5]. | [1], [5], [10] | Candidate (unverified)
CAN-FD | Yes -- CAN peripheral supports CAN-FD, ISO 11898-1:2015 [1] §8.26, p.68 | ADM3055E / ADM3057E [10] (isolated transceiver, candidate) | Configure MCU CAN peripheral for FD frames (up to 5Mbit/s); select isolated CAN-FD transceiver; per [6]. | [1], [6], [10] | Candidate (unverified)
MIL-STD-1553B | No -- needs dedicated 1553 interface module | Alta MEZ-E1553 [11] (candidate host-interface module) | Select 1553 interface module; confirm target revision (1553B vs. 1553C, open per TODO.md 1.7); per [7]. | [7], [11] | Candidate (unverified)

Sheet: Control
Control Loop Decision Matrix
Build axis: Control (Open / Closed-Diff / Closed-PID)
Control Mode | Feedback Method | Additional BOM Component | Firmware Workflow Steps | REFERENCES.md Tags | Status
Open-loop | None -- fixed commanded duty cycle, no feedback | None | Map input protocol command directly to PWM duty cycle; no observer or control-law firmware needed. | - | No part needed
Closed-loop differential | Sensorless FOC observer (TI SLAAE96A [13]) using MCU's own ADC / OPA / COMP peripherals ([1] p.77, Table 10-1: 2xADC, 2xOPA, 3xCOMP) | None (sensorless); fallback candidate: TI DRV5013 Hall sensor [13] | Implement rotor position/speed observer per SLAAE96A; compute differential (measured vs. commanded) speed error each control cycle; no proportional/integral tuning beyond differential term. | [1], [13] | Candidate (unverified)
Closed-loop PID | Same sensorless FOC observer as Closed-loop differential ([13]) | None (sensorless); fallback candidate: TI DRV5013 Hall sensor [13] | Same observer as above; add integral and derivative terms to the control law; tune PID gains against the amperage/voltage tier's motor and load characteristics. | [1], [13] | Candidate (unverified)

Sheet: EMI Hardening
EMI Hardening Tier Decision Matrix
Build axis: EMI Hardening (None / Isolation / Grounding / Faraday)
Tier | Governing Standard(s) | BOM Component | Purchasable Part? | Workflow Steps | REFERENCES.md Tags | Status
None | - | None | No | No additional EMI mitigation beyond standard PCB layout practice. | - | No part needed
Isolation | IEC 62368-1:2018 [16] (basic/reinforced insulation classification) | ADuM4221 isolated gate driver [18] (candidate) | Yes | Select isolated gate driver / digital isolator for gate-drive and/or feedback signal paths; verify UL1577 proof-test rating and creepage/clearance per [16]; scope which signal class(es) the tier covers before final part selection. | [16], [18] | Candidate (unverified)
Grounding | MIL-STD-461G [15] (general bonding requirements); IEC/TR 61000-5-2:1997 [17] (earthing/cabling installation guideline) | None -- layout/practice only | No | Apply single-point ground topology, continuous ground-plane layout, and star-grounding of high-di/dt power-stage return paths per [15]/[17]; no purchasable component implements this tier. | [15], [17] | No part needed
Faraday | MIL-STD-461G [15] (shielding/radiated-emissions rationale, e.g. RE102/CE102 test methods) | Würth Elektronik WE-SHC 3671375 shielding cabinet [19] (candidate) | Yes | Select board-level shielding can sized to cover the gate-drive / high-di/dt switching node area; verify shielding effectiveness (dB) over the target frequency range per [15]'s emissions rationale. | [15], [19] | Candidate (unverified)

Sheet: Wire Egress
Wire Egress Decision Matrix
Build axis: Wire Egress (Opposite-end / Same-end, opposite faces)
Egress Pattern | Terminal Face Assignment | Board Re-partition Required | Inner-Plane Shield Requirement | Additional BOM Component | Workflow Steps | REFERENCES.md Tags | Status
Opposite-end (default) | Pack J5A/J5B on F.Cu at one board end; phases J4A/J4B/J4C on F.Cu at the other. Both groups sit directly on their own pours. | None. This is the as-built arrangement on builds/6s/50A/CAN_485_faraday/. | None arising from egress. The In1.Cu GND plane and the In2.Cu GND pour above y 60.5 mm serve their normal return and shielding roles; no terminal group is stacked over another. | None beyond the selected EMI Hardening tier | No egress-specific step. Terminal placement follows the power-stage placement; verify each terminal lands on its own pour per docs/tools/conductor_sizing.py. | - | Candidate (unverified)
Same-end, opposite faces | Both groups leave the same board end. Phases J4A/J4B/J4C stay on F.Cu on their existing pours (unchanged); pack J5A/J5B move to B.Cu directly opposite. The two inner GND planes lie between them. | Yes. B.Cu at the terminal end currently holds the MCU U1, the secure element U2 and the probe pads J1; all three must vacate to the logic end. VM distribution must also be extended to reach a B.Cu pad at that end -- today the VM pour stops at y 60.3 mm (F.Cu) / 60.5 mm (In2.Cu). | MANDATORY and NOT currently met. The unnamed rule area at x 20.75-51.15, y 76.50-86.55 mm sets `copperpour not_allowed` on ALL FOUR copper layers, so In1.Cu and In2.Cu are cut away exactly where the two terminal groups would face each other. That rule area must be restricted to the outer layers, the inner GND planes must pour solid through the terminal window, and phase via transitions must be kept out of that window so no antipad perforates the shield. | Common-mode choke on the pack input -- TBD -- requires primary-source verification (AGENTS.md Sec.1.3). No choke has been sourced or verified in this repo. | Define a stackup FIRST -- the board currently has none (4 copper layers declared, `(thickness 1.6)` is KiCad's default, no dielectric height or copper weight specified). Then: fix the rule area's layer scope; re-place U1/U2/J1; extend VM to B.Cu; stitch In1/In2 with a GND via fence around the terminal window; re-run conductor_sizing.py and isolation_envelope.py; negative-control every new DRC rule before trusting it. | [9], [49] | Open / unresolved
Note: Rejected third arrangement: same end, both groups on the outer faces but split onto the two long edges. Five terminals in one row need 2 x 7.0 mm + 3 x 5.0 mm = 29.0 mm of pad on a 32.00 mm edge, leaving 0.50 mm per gap once four inter-pad gaps and two edge margins are taken -- not dressable with 6 sq.mm (~10 AWG) conductor, its solder fillet and its strain relief. Widening the board to suit is governed by docs/solutions/architecture-patterns/isolation-geometry-sets-board-aspect.md, which prices width at 3.0x the length it saves. See docs/design-single-end-wire-egress-variant.md Sec.7.2. -- Board thickness is NOT a usable lever for face-to-face separation: with a grounded plane between the faces the direct coupling path is already terminated, whereas doubling the laminate thickness only halves a parallel-plate capacitance. Restore the plane rather than thicken the board.
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

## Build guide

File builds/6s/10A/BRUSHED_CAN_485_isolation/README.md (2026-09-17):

# Build: 6S / 10A / BRUSHED / CAN-FD + RS-485 / Isolation

Governed by `AGENTS.md`. This document is the per-build instantiation of the
axis options in the repo-root `README.md`, produced by walking
`docs/decision-matrix.xlsx` (exported to `docs/decision-matrix.json`,
2026-09-17) for each requested axis. It is the descriptive counterpart to
`kicad/` (schematic, ERC-clean) and `gerbers/` (empty until a layout exists).

**Host:** the Serenity-UAV nacelle-tilt actuator, two boards per aircraft
(port and starboard). The host's requirements are carried in
"Host constraints" below and trace to the Serenity-UAV plan
`docs/plans/2026-09-17-001-feat-tilt-controller-open-secure-esc-build-plan.md`
(cited there as `REF-ESC-001`). This build is the first brushed-DC instance,
the first 10 A-tier instance, and the first instance of the Holding Brake
axis.

**AI note:** authored by Claude Opus 5 (Anthropic, `claude-opus-5`) under the
direction of Steve Griffing, PE(CSE), CISSP-ISSEP, CPP, 2026-09-17. Not yet
human-reviewed.

## Requested build parameters

| Axis | Selection | Matrix row (`docs/decision-matrix.json`) |
| --- | --- | --- |
| Voltage | 6S — 22.2 V nominal, 25.2 V full charge, 15 V cutoff | `voltage.6s` |
| Amperage | 10 A tier — governs copper and connector class only; the power stage comes from the Motor sheet (brushed override note on the Amperage sheet) | `amperage.10` |
| Motor | Brushed (DC) — single integrated H-bridge, 0 shunts | `motor.brushed_dc` |
| Shaft sensor | Magnetic absolute (SPI/SSI), remote — AEAT-8800-Q24 off-board | `shaft_sensor.magnetic_absolute_spi_ssi` |
| Holding brake | Low-side solenoid driver, spring-applied — de-energised = engaged | `holding_brake.low_side_solenoid_driver_spring_applied` |
| Protocol | CAN-FD **and** RS-485, both present concurrently | `protocol.can_fd`, `protocol.rs_485` |
| Control | Closed-loop PID — inner loop on the remote encoder, outer loop on a host angle received over the bus | `control.closed_loop_pid` |
| EMI hardening | Isolation — isolated transceivers, no Faraday cabinet | `emi_hardening.isolation` |
| Wire egress | Opposite-end (default) — power/motor on one end, bus/encoder on the other, both on the host's permitted edges | `wire_egress.opposite_end_default` |
| Form factor | Flat (default) | `form_factor.flat_default` |

## Bill of materials

Every line carries its `REFERENCES.md` tag and the matrix row's Status.
`Verified (local PDF)` means the primary datasheet is in `docs/datasheets/`
and the cited figure was read from it. Passive values are engineering
defaults unless a datasheet fixes them (each schematic part carries a
`Note` property saying which).

### MCU / trust anchor (common to all builds)

| Ref | Part | Qty | Citation | Status |
| --- | --- | --- | --- | --- |
| U1 | TI MSPM0G3518-Q1, RHB (VQFN-32), `M0G3518QRHBRQ1` | 1 | [44] | Verified (local PDF) — tilt-build role symbol `symbols/specs/MSPM0G3518_Q1_RHB_TILT.json`, all 32 pins verified against [44] Fig. 6-6 / Table 6-2 |
| U2 | Infineon OPTIGA™ Trust M V3, SLS 32AIA010ML | 1 | [45] | Verified (local PDF); circuit per [45] p.12 Fig. 2 as on the 6S/50A build |
| C15 | 470 nF ±20 % VCORE tank | 1 | [44] | Verified (value required by [44], see the 50A build README) |
| C16, R25, C17 | VDD decoupling, NRST pull-up/filter | 3 | — | Generic |
| R26, R27, C18 | I²C pull-ups, OPTIGA decoupling | 3 | [45] | Generic values; topology per [45] Fig. 2 |
| J4 | SWD header 1×4, 1.27 mm | 1 | — | Generic |

### Power stage — Motor: Brushed (DC), Tier 1

| Ref | Part | Qty | Citation | Status |
| --- | --- | --- | --- | --- |
| U5 | TI DRV8874-Q1 integrated H-bridge, HTSSOP-16 PWP, 4.5–37 V, 6 A peak, PH/EN mode | 1 | [62], [63] | Verified (local PDF); footprint from TI's PWP0016J land pattern |
| C11 | CVM1 100 nF 50 V at VM | 1 | [63] Table 7-1 | Verified |
| C5, C6 | CVM2 bulk 22 µF 16 V ×2 on VMOT (sized per [63] §9.1 in the layout follow-up) | 2 | [63] | Value pending |
| C12 | CVCP 100 nF 16 V, VCP–VM | 1 | [63] Table 7-1 | Verified |
| C13 | CFLY 22 nF 50 V, CPH–CPL | 1 | [63] Table 7-1 | Verified |
| R13 | RnFAULT 10 kΩ pull-up to 3V3 | 1 | [63] Table 7-1 | Verified (IOD ≤ 5 mA) |
| R18 | RIMODE 62 kΩ to GND — quad-level 3: cycle-by-cycle chopping, latched-off OCP, nFAULT reports chopping | 1 | [63] Table 7-6 | Verified (KTD15) |
| — | PMODE strapped to GND — PH/EN control mode | — | [63] Table 7-2 | Verified |
| R14, R15 | VREF divider from 3V3 (sets ITRIP = VVREF / (AIPROPI · RIPROPI)) | 2 | [63] Eq. 3 | Values pending — ITRIP set just above the 2.9 A motor stall (stall backstop, not a working limit) |
| R16 | RIPROPI to GND (VIPROPI = IPROPI · RIPROPI, AIPROPI 450 µA/A) | 1 | [63] §7.3.3.1 | Value pending — ~2.5 V at ITRIP |
| R17, C14 | IPROPI RC filter into ADC A0_3 | 2 | — | Generic |
| J2 | Motor connector 1×2 | 1 | Serenity REF-ACT-001 | Pololu 20D 25:1 CB 6 V #3712 — 2.9 A stall, 0.74 A max-efficiency, 0.15 A free-run; sense declared per side in firmware |

The Amperage sheet's IRFB4110 / DRV8353S / WSLP2512 / INA240 columns do not
apply (brushed override, `docs/decision-matrix.xlsx` Amperage notes).

### Power rails — 6S in, buck to VMOT and 3V3

| Ref | Part | Qty | Citation | Status |
| --- | --- | --- | --- | --- |
| J1 | VBAT input 1×2 (the 3 A branch fuse is in the host harness) | 1 | Serenity `POWER_DISTRIBUTION.md` §3.3a | Connector class placeholder |
| C1, C2 | Input bulk 10 µF 50 V + 100 nF | 2 | [65] §8.2 | Generic |
| U6 | TI TPS54560B, 4.5–60 V in, 5 A, HSOIC-8 DDA — **VMOT 6.5 V** motor/solenoid rail | 1 | [65] | Verified (local PDF); footprint from TI's DDA0008B land pattern |
| U8 | TI TPS54560B — **3V3** logic rail (same part for BOM commonality; judgment call, `AGENTS.md` §4) | 1 | [65] | Verified (local PDF) |
| R1/R2, R7/R8 | EN/UVLO dividers | 4 | [65] §7.3.7 | Values pending (design procedure) |
| R3, R9 | RT/CLK 500 kHz | 2 | [65] §7.3.9 | Values pending |
| R4/R5, R10/R11 | FB dividers, VOUT = 0.8 V·(1 + RHI/RLO) | 4 | [65] §7.3.6 | Values pending |
| R6/C3, R12/C7 | Type-II compensation | 4 | [65] §8.2.2.7 | Values pending |
| C4, C8 | BOOT 100 nF | 2 | [65] §7.3.4 | Verified (value) |
| L1, L2 | Buck inductors | 2 | — | **UNVERIFIED — needs primary source (see TODO.md 18.3)**: part not selected; ≤ 4 mm height on the web-facing side is a hard host constraint |
| D1, D2 | Catch diodes, ≥ 60 V, ≥ 5 A avg | 2 | — | **UNVERIFIED — needs primary source (see TODO.md 18.3)** |
| C9, C10 | 3V3 output bulk + bypass | 2 | — | Generic |
| R21/R22 | VMOT sense divider → ADC A1_12 | 2 | — | Generic (KTD9 rail-droop rule) |
| R23/R24 | VBAT sense divider → ADC A1_7 | 2 | — | Generic |

### Holding brake — low-side solenoid driver

| Ref | Part | Qty | Citation | Status |
| --- | --- | --- | --- | --- |
| U7 | TI TPL7407L, TSSOP-16 — IN1+IN2 paralleled on `BRAKE_EN`, OUT1+OUT2 sink the coil, COM = VBAT | 1 | [66] | Verified (local PDF): 600 mA/ch, parallelable (§7.1), 1 MΩ input pull-down (§7.3), clamp diodes to COM, COM 8.5–40 V (§6.3) |
| R32 | External `BRAKE_EN` pull-down 100 kΩ | 1 | — | Generic (KTD9: MCU reset / Hi-Z = brake engaged) |
| R19/R20 | Brake-state readback divider on `SOL_N` → ADC A0_7 | 2 | — | Generic |
| J3 | Solenoid connector 1×2 (VMOT, SOL_N) | 1 | — | Generic |
| — | Pull solenoid itself | — | Serenity BRK-4 | **Host-side part, not in this BOM**; hold-in / dropout voltage to be recorded under BRK-4 |

### Shaft sensor — magnetic absolute, remote

| Ref | Part | Qty | Citation | Status |
| --- | --- | --- | --- | --- |
| J7 | Encoder header 1×6, 1.25 mm keyed: 3V3, GND, SCLK, DO, NSL, DI | 1 | [64] | Connector class placeholder |
| R28–R31 | 33 Ω series on the four SPI lines | 4 | `docs/design-speed-sensor-integration.md` | Generic |
| (off-board) | Broadcom AEAT-8800-Q24 on the sensor daughter in the host's brake guide, ~35 mm cable | — | [64] | Verified (local PDF); symbol `symbols/AEAT_8800_Q24.kicad_sym` carried for the daughter |

### Protocol — CAN-FD + RS-485, Isolation tier

| Ref | Part | Qty | Citation | Status |
| --- | --- | --- | --- | --- |
| U3 | ADI ADM3057E isolated CAN-FD transceiver (chosen over ADM3055E: identical timing, lower creepage) | 1 | [6], [10] | Candidate (unverified) — same standing as on the 6S/50A build; pin map VERIFIED |
| U4 | ADI ADM2587E isolated RS-485 transceiver, half-duplex (Y/A, Z/B tied) | 1 | [4], [9] | Candidate (unverified); pin map VERIFIED |
| FB1–FB4 | Murata BLM15HD182SN1D ferrites on the isolated supplies and grounds | 4 | [53] | As the 6S/50A build ([10] p.25) |
| C19–C26 | 10 µF + 100 nF reservoirs on VISOIN/VISOOUT, both transceivers | 8 | [9], [10] | As the 6S/50A build |
| J5, J6 | CAN (H/L) and RS-485 (A/B) connectors 1×2 | 2 | — | Generic |

Isolation creepage: 7.5 mm ([9] Table 6) is the binding figure; the board
width check is in `kicad/README.md`.

### Host I/O

| Ref | Part | Qty | Citation | Status |
| --- | --- | --- | --- | --- |
| J8 | Differential-tilt trip input 1×2 → PA7 | 1 | Serenity `TILT_DRIVE_CONTROL_SPEC.md` §5.4 | Executor and independence to be defined (TILT-CTL-02) |

## Host constraints — Serenity-UAV nacelle tilt (Rev T5e)

Source: Serenity-UAV `airframe/openscad/fuselage/cargo/tilt_actuator_bracket.scad`
(`BOARD_*`, `RAIL_*`), `tools/cargo_layout_fit.py` (`BOARD_L`, `BOARD_W`,
`BOARD_T`), `docs/TILT_ACTUATOR_SELECTION.md` §4–§6,
`docs/TILT_DRIVE_CONTROL_SPEC.md` §1, §5.2–§5.5, `docs/POWER_DISTRIBUTION.md`
§3.3a. Units imperial-primary per the host's convention.

| Constraint | Value | Why |
| --- | --- | --- |
| Board outline | ≤ 1.69 × 1.44 in (42.9 × 36.5 mm), no mounting holes needed | Card-edge rails on the bracket web's outboard face; board slides in along +Y, retained by a cable tie |
| Component height, web-facing side | ≤ 0.16 in (4.0 mm) (`RAIL_H`) | Standoff between the component side and the bracket web; the envelope has 0 mm to spare outboard |
| Back face | Bare (no components) | Faces the hull skin |
| Connector edges | Aft (+Y) or inboard (−X) only | The outboard edge faces the 2 mm rail lip |
| Feed | VBAT 22.2 V nominal / 25.2 V full, own fused branch `F_TILT_P` / `F_TILT_S`, 3 A mini blade in the harness | Per-path fusing so no single failure cascades; the buck's current limit and soft-start, not the fuse, bound the rail |
| Motor | Pololu 20D 25:1 CB 6 V (#3712): 2.9 A stall, 0.74 A max-eff, 0.15 A free-run | REF-ACT-001; six-start worm, 23.8:1 overall |
| Solenoid | ~0.5 A at 6 V continuous or PWM-held, pull type, Ø12 × 24 mm class | BRK-4 (part open on the host side) |
| Sensor | AEAT-8800-Q24 in the brake guide reading a Ø6 diametric magnet in the worm's brake collar; ~1.38 in (35 mm) cable | `TILT_ACTUATOR_SELECTION.md` §4; 9.6 turns over the sweep, firmware accumulates turns |
| Outer loop | AK7455 nacelle angle, signed by the nacelle gateway, received over CAN-FD | `CAN-PERIPH-GW-1.md` Deployment §1; the angle frame is a trust boundary the controller verifies |
| Sense | Actuator-positive = nacelle-positive on **port**; **starboard reversed** (same right-hand worm, mirrored bracket) — declared per side in firmware, never discovered | `tilt_actuator_bracket.scad` header (TC-6) |
| Thermal | ≈ 2 W in the DRV8874-Q1 at stall (2.9 A² × 0.24 Ω) with the component side facing the web at 4 mm | [63] §8.2.1.2 thermal design; thermal vias under the PWP pad at layout |

### Fail-state table (owner: Serenity plan, System-Wide Impact)

| Event | Motor (DRV8874-Q1) | Brake | Bus sees |
| --- | --- | --- | --- |
| Branch fuse opens | VM → 0, UVLO, all FETs off ([63] §7.3.4.1) | Engages (coil unpowered) | Node silent |
| Buck U6 fails open | as above | Engages; MCU alive on 3V3 | nFAULT + brake state, node alive |
| VMOT droop (stall / current limit) | drives down to VUVLO 4.35 V typ ([63] §6.5) | may drop out above UVLO → firmware: on `ADC_VM` < V_hold, EN = 0 (slow decay) before the coil drops out | VM alarm |
| OCP / TSD / CPUV | all FETs off, latched (level 3, [63] Table 7-6/7-7) | released until firmware engages it on nFAULT | fault frame |
| ITRIP chopping (jam) | slow-decay chopping ([63] §7.3.3.2.1) | released | nFAULT + IPROPI |
| MCU reset / brown-out | all FETs off via input pull-downs ([63] §7.3.2) | engages: R32 + TPL7407L internal pull-down | node off the bus |
| Bus lost | inner loop holds on the encoder | engage after timeout, then nSLEEP | — |
| Differential-tilt trip | undefined (TILT-CTL-02) | if "engage both": a bus command with latency + authorization | trip frame |

**Fail-safe resolution for this build** (`docs/design-brushed-esc-variant.md`
"Safety & failure modes", `TODO.md` 12.3.a): fail-safe = brake engaged,
motor coasting. Fail-operational applies only to a MAC failure on a position
frame (hold the last valid command; never engage mid-manoeuvre).

## Firmware requirements (recorded, not implemented)

Owner of each rule is the Serenity-UAV document cited; this list is the
build's contract, not a restatement.

1. Cascade: inner velocity/position loop on the AEAT-8800 worm-shaft angle
   (turns accumulated in firmware, homed from the outer sensor); outer loop
   on the AK7455 nacelle angle received over CAN-FD — `TILT_DRIVE_CONTROL_SPEC.md` §1–§2.
2. Brake sequencing: release → move → settle → engage, where "settled" comes
   from the encoder (worm stationary) and "unloaded" from the AK7455 over
   the bus, never from IPROPI ([63] §7.3.3.1 reports one low-side FET in
   slow decay). Sequence on release: EN = 0 (damp) → encoder stationary →
   `BRAKE_EN` low → `nSLEEP` low (tSLEEP, [63] §6.5) — spec §5.2 (BRK-1..3).
3. `MOT_nFAULT` (PA26, TIMA_FAL0) is a brake-engage input; the latency budget
   plus the pin's mechanical engage time is set here — spec §5.3.
4. Rail droop: on `ADC_VM` below the solenoid hold-in voltage (BRK-4), EN = 0
   before the coil drops out.
5. Jam detection: IPROPI current at or near ITRIP with the AK7455 static → stop
   commanding into it (latched OCP mode ensures the bridge does not hammer
   the train at 500 Hz) — spec §5.3; KTD15.
6. Differential-tilt trip input on `TRIP_IN` (PA7) — spec §5.4; executor
   and independence to be defined (TILT-CTL-02).
7. Per-side sense declaration (starboard reversed) — TC-6.
8. Bus security: brake release is a distinct authenticated command class with
   its own freshness counter and an arm/confirm pair, in the per-frame CMAC
   hot path (never an OPTIGA private-key operation — `docs/secure-element-architecture.md`,
   5 s protected-op budget). Asymmetric fail policy: MAC failure on a
   position frame → fail-operational on the last valid command; MAC failure
   on a release → stay engaged. Symmetric path is the MSPM0 AES-CMAC engine,
   pending `TODO.md` 13.1.e — spec §5.5 (TILT-CTL-09).
9. Bus loss: engage after a timeout, then sleep the bridge — spec §5.1/§5.2.

## Open items (not resolved in this document)

| # | Item | Tracked |
| --- | --- | --- |
| 1 | Buck inductors L1/L2 and catch diodes D1/D2 — select against ≤ 4 mm height, fetch primary datasheets | `TODO.md` 18.3 |
| 2 | Buck design values (UVLO, RT, FB, compensation) per [65] §8.2 | `TODO.md` 18.3 |
| 3 | ITRIP / RIPROPI / VREF values against the 20D's 2.9 A stall | `TODO.md` 18.3 |
| 4 | Country-of-origin (fab / assembly) for U5–U8 and the AEAT-8800 | `TODO.md` 18.4 |
| 5 | AEAT-8800 land pattern (Broadcom Fig. 17) vs the KiCad stock QFN-24 | `TODO.md` 18.5 |
| 6 | Connector part numbers (J1–J8) against the Serenity harness spec | `TODO.md` 18.3 |
| 7 | PCB layout, routing, DRC, thermal vias, Gerbers | `TODO.md` 18.6 |
| 8 | Firmware (items 1–9 above) | `TODO.md` 8.7 |
| 9 | ADM3057E / ADM2587E part-selection status is still Candidate, as on the 50A build | `TODO.md` 6.7–6.9 |

## Folder contents

| Path | What it is |
| --- | --- |
| `README.md` | This document |
| `kicad/README.md` | Schematic status, file list, library bindings, envelope check |
| `kicad/open_secure_esc_6s_10a_brushed_can485_iso.kicad_sch` | Schematic, generated — ERC 0 errors / 0 warnings (KiCad 9.0.2) |
| `kicad/open_secure_esc_6s_10a_brushed_can485_iso.kicad_pro` | Project: net classes (Power / Motor / Isolated / Sense) |
| `kicad/open_secure_esc_6s_10a_brushed_can485_iso.kicad_dru` | Custom rules: conductor spacing, isolation-barrier via check |
| `kicad/sym-lib-table`, `kicad/fp-lib-table` | Bindings to `symbols/` with citation notes |
| `kicad/tools/gen_schematic.py` | The schematic's single source; `--check` proves the committed sheet matches |
| `gerbers/README.md` | Empty by design — see the file |

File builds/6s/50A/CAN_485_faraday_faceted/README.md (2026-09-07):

# Build: 6S / 50A / CAN-FD + RS-485 / Faraday / Opposite-end egress / Faceted

Governed by [`AGENTS.md`](../../../../AGENTS.md). Per-build instantiation of
the axis options in the repo-root [`README.md`](../../../../README.md).

**Parent build:** [`../CAN_485_faraday/`](../CAN_485_faraday/) — the original
build, **opposite-end** wire egress (pack in at one board end, phases out at
the other; this is the `Wire Egress = Opposite-end` default, carrying no
suffix in the parent's own name). This variant differs on the **Form
Factor** axis and inherits the parent's entire BOM and schematic. The BOM is
deliberately **not** duplicated here.

**Sibling build:**
[`../CAN_485_faraday_sameend_faceted/`](../CAN_485_faraday_sameend_faceted/)
— the same Form Factor value applied to the **same-end** egress parent
instead. Both faceted builds share an identical component set and an
identical functional partition (below), because both parent boards are
instantiated from the same schematic and differ only in where the five power
conductors terminate — a fact this build's placement run confirms rather
than assumes.

**Status: INITIAL PLACEMENT DONE. Not routed. Not fabricable.** Every
footprint is placed inside a 23.00 mm strip with zero courtyard overlaps and
zero DRC errors. No copper, no stackup, no interconnect part. AI-generated
by **Claude Opus 5** (Anthropic), 2026-09-05. Not human-reviewed.

## Requested build parameters

| Axis | Selection | Same as parent? |
| --- | --- | --- |
| Voltage / Amperage | 6S / 50A | yes |
| Protocol | CAN-FD **and** RS-485 | yes |
| EMI Hardening | Faraday | yes |
| Wire Egress | Opposite-end (default) | yes |
| **Form Factor** | **Faceted** (two panels, placed) | **NO — this variant** |

## 1. Functional partition and placement, run fresh against this parent

[`docs/tools/facet_placement.py`](../../../../docs/tools/facet_placement.py)
re-derives the functional partition from **this** board's own netlist —
it does not assume the sibling build's assignment — and produces:

```text
Panel P (power stage): 30 parts, 23.00 x 89.51 mm
  rotated 90 deg to fit strip width: SH1
Panel L (logic/comms):  35 parts, 23.00 x 61.68 mm
```

**Identical to the same-end sibling build's numbers**, part-for-part and
millimetre-for-millimetre. That is not a coincidence to wave past: it is the
expected result, because Wire Egress only relocates the five terminal
footprints and their local copper — it changes nothing about which
components exist, which nets connect them, or the functional partition rule
(named power-stage/logic-comms cores, then net-majority propagation).
Confirming the two runs agree is what makes it safe to say the Form Factor
axis and the Wire Egress axis are **independent** on this design: choosing
one does not silently constrain the other.

## 2. Panel envelopes, as placed

| | Panel P | Panel L |
| --- | --- | --- |
| Parts | 30 | 35 |
| Strip width | 23.00 mm | 23.00 mm |
| Length (component-driven) | 89.51 mm | 61.68 mm |
| Combined envelope (side by side, 3 mm gap) | 49.00 × 89.51 mm | |

See the sameend-faceted sibling's README §2 for the placement-floor caveat
(this is a greedy shelf-pack, not a routing-aware layout) and the SH1
rotation rationale (§1 there) — both apply here unchanged.

## 3. Verification performed

Toolchain: KiCad **9.0.2** throughout. Output board remains
`version 20241229` / `generator_version "9.0"` — not advanced to KiCad 10.

| Check | Result |
| --- | --- |
| Courtyard overlaps (all 65 parts, both panels) | **0** |
| DRC errors | **0** |
| DRC warnings | 43 (`silk_edge_clearance` 7, `silk_over_copper` 23, `silk_overlap` 13 — all silkscreen, expected) |
| Unconnected items | 184 (expected — no copper exists yet) |
| Board format after write | `version 20241229` / `"9.0"` — unchanged |

## 4. What is not done

Same open list as the same-end sibling build (§4 there): no routing, no
stackup (`TODO.md` 15.2), SH1's rotated shielding geometry unverified against
the gate-drive loop, no interconnect part selected, panel length not
routing-aware, host envelope unconfirmed (`TODO.md` 16.3), and no mounting
scheme (`TODO.md` 16.4h).

**One item specific to this egress variant:** the opposite-end parent's
terminal geometry (pack and phase conductors at opposite board ends, per the
original build) has not been re-examined for whether it changes anything
about where the functional partition's panel boundary should physically fall
relative to the terminals once real placement — not just the functional
grouping — is considered. §1 confirms the *grouping* is identical; it does
not by itself confirm the *panel boundary location relative to each
terminal* is equally sensible for both egress variants.

## 5. Reproducing this placement

```bash
python3 docs/tools/facet_placement.py \
    --board builds/6s/50A/CAN_485_faraday/kicad/open_secure_esc_6s_50a_can485_faraday.kicad_pcb \
    --output kicad/open_secure_esc_6s_50a_can485_faraday_faceted.kicad_pcb \
    --strip-width 23.0 --gap 3.0 \
    --json kicad/placement.json
```

KiCad **9.0.2** only — see
[`docs/solutions/architecture-patterns/pcbnew-bulk-removal-segfault.md`](../../../../docs/solutions/architecture-patterns/pcbnew-bulk-removal-segfault.md)
for a pcbnew scripting trap this tool works around.

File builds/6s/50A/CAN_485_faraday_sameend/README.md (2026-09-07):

# Build: 6S / 50A / CAN-FD + RS-485 / Faraday / Same-end egress

Governed by [`AGENTS.md`](../../../../AGENTS.md). Per-build instantiation of
the axis options in the repo-root [`README.md`](../../../../README.md),
walked from [`docs/decision-matrix.xlsx`](../../../../docs/decision-matrix.xlsx).

**Parent build:** [`../CAN_485_faraday/`](../CAN_485_faraday/). This variant
differs on exactly one axis — **Wire Egress** — and inherits that build's
entire BOM, schematic and verification state. The BOM is deliberately **not**
duplicated here; it would drift. Read the parent's `README.md` for every part
and its citation, and treat this document as the delta only.

**Status: NOT READY FOR FABRICATION.** Geometry is applied and DRC-clean of
errors; two nets at the new terminal end are still unconnected by design (§4),
and the board has no stackup (§5). AI-generated by **Claude Opus 5**
(Anthropic), 2026-08-31. Not human-reviewed.

## Requested build parameters

| Axis | Selection | Same as parent? |
| --- | --- | --- |
| Voltage | 6S | yes |
| Amperage | 50A | yes |
| Protocol | CAN-FD **and** RS-485 | yes |
| Control | *not specified* | yes |
| EMI Hardening | Faraday | yes |
| **Wire Egress** | **Same-end, opposite faces** | **NO — this variant** |

## 1. What "same-end, opposite faces" means here

All five 50 A conductors leave the same board end, for a pocket (blind-cavity)
installation with no access to the far end. The two groups are separated by
putting them on **opposite faces** with the board's two inner GND planes
between them:

| Conductor | Net | Face | Position |
| --- | --- | --- | --- |
| `PH_A` | phase A | F.Cu | (25.45, 90.50) mm |
| `PH_B` | phase B | F.Cu | (35.95, 90.50) mm |
| `PH_C` | phase C | F.Cu | (46.45, 90.50) mm |
| `VM` (VBATT+) | pack + | **B.Cu** | (30.95, 90.50) mm |
| `GND` (VBATT−) | pack − | **B.Cu** | (40.95, 90.50) mm |

Rationale, coupling arithmetic, and the rejected alternatives are in
[`docs/design-single-end-wire-egress-variant.md`](../../../../docs/design-single-end-wire-egress-variant.md).

## 2. The board is longer, not re-partitioned

The design document's original plan moved `U1`/`U2`/`J1` to the logic end to
free the terminal end. **That plan is dead.** `U1`'s courtyard measures
13.45 mm, not the 12.90 mm the envelope calculation assumed, so with `U1` at
the logic end `docs/tools/isolation_envelope.py` returns:

```text
13.45 + 2 x (7.5 + 1.43) + 2 x 0.55 = 32.41 mm minimum board width
```

against an actual 32.00 mm — a **0.41 mm failure**. The 7.5 mm creepage
underneath it is REFERENCES.md [9] Table 6, a verified primary-source value,
so the board width cannot absorb it. The design document's own instruction for
this case is explicit: *"this variant needs a different partition, not a wider
board."*

The different partition is to leave the logic cluster where it is and buy
**length** at the terminal end. `isolation_envelope.py` prices width against
length at 2.7× on this geometry, so length is the cheap dimension.

| | Parent | This variant |
| --- | --- | --- |
| Board outline | 1.260 × 2.602 in (32.00 × 66.10 mm) | 1.260 × 2.996 in (32.00 × 76.10 mm) |
| Board area | 3.28 in² (2115 mm²) | 3.77 in² (2435 mm²), **+15.1 %** |
| `U1` / `U2` / `J1` | B.Cu, y ≈ 76–86 mm | **unchanged** |
| MCU → gate-driver run | ≈18.5 mm | **unchanged** |
| Current-sense returns | — | **unchanged** |

Leaving the logic cluster alone also drops both regressions the original
partition carried.

Applied by [`kicad/tools/make_same_end_egress.py`](kicad/tools/make_same_end_egress.py).

## 3. Inner planes are the interface shield

At the terminal end `In1.Cu` and `In2.Cu` are both solid GND, so two grounded
planes lie between the phase pads on F.Cu and the pack pads on B.Cu. A
grounded plane does not attenuate the field between two conductors — it
terminates it.

This only works because the inner-layer copper-pour keepout was removed from
the parent build first (commit `4baa178`,
[`../CAN_485_faraday/kicad/tools/restore_inner_planes.py`](../CAN_485_faraday/kicad/tools/restore_inner_planes.py)).
Before that, the rule area forbade pour on **all four** copper layers across
the terminal window, so the shield had a hole in it exactly where this variant
needs it. Probe points inside the window went 0/6 → 6/6 in copper on both
inner planes.

## 4. Open: VM distribution to the relocated pack pad

**Two nets at the new terminal end are unconnected, both known and neither
bridged by guesswork.**

| Net | Pad | Why |
| --- | --- | --- |
| `VM` | `J5A` pin 1 | The VM pour stops at y 60.3 mm (F.Cu) and y 60.5 mm (In2.Cu); B.Cu from y 60.5 mm to the board end is GND. Carrying VM to a B.Cu pad in the new terminal band re-partitions a plane, which depends on a stackup this board does not have (§5). |
| `GND` | `J5B` pin 1 | The outer-layer rule area moved with the terminal band and now blocks the B.Cu GND pour from reaching the pad — the same defect `TODO.md` 12.5.an measures on the parent, where pour meets a J4 pad over 1.00 mm of a 10 mm pad. |

Neither was closed with a track. `docs/tools/conductor_sizing.py` shows a
0.118 in (3.0 mm) track across that span costs 11.36 W across three phases —
more than all six TPHR8504PL FETs' 10.5 W conduction loss combined. That
copper must be pour, or the terminal must sit on the pour's layer.

Both point at the same unresolved decision: `TODO.md` 12.5.ae, whether the
outer-layer (F.Cu/B.Cu) extent of the rule area should be deleted or shrunk.
That moves 50 A current paths and is reserved for sign-off. **This build
inherits that open decision from its parent.**

## 5. Open: the board has no stackup

The `.kicad_pcb` declares four copper layers and carries `(thickness 1.6)` in
its `general` block, which is KiCad's default rather than a design decision.
No dielectric height, copper weight, laminate permittivity or surface finish
is specified anywhere in this repository. Tracked as `TODO.md` 15.2; it gates
the copper-weight and fabrication decisions.

## 6. Verification state

Toolchain pinned to **KiCad 9.0.2** throughout (`/usr/bin/kicad-cli`,
`pcbnew 9.0.2+dfsg-1`). The board file remains `version 20241229` /
`generator_version "9.0"` and has **not** been advanced to KiCad 10.

| Check | Parent | This variant |
| --- | --- | --- |
| DRC violations | 20 | **20** |
| DRC errors | 0 | **0** |
| DRC warnings | 20 (11 silk_over_copper, 7 silk_overlap, 2 isolated_copper) | identical |
| Unconnected items | 151 | **150** |

The two `solder_mask_bridge` errors introduced by the first geometry pass were
traced to fiducials `FID3`/`FID6`, which sat inside the old rule-area band and
were engulfed once that band flooded with copper. They move with the band;
step 6 of the tool does this and the errors are gone.

**Routing is not complete on either build** — 150 unconnected items is
inherited, not caused by this variant. This build is not a routed board and
must not be read as one.

## 7. Not done

- Routing and re-pour after route (parent is also unrouted).
- Gerber generation — `gerbers/` is a placeholder.
- Connector selection: `J4`/`J5` are still bare solder-wire pads
  (`TODO.md` 12.4.l), and single-end egress tightens the constraint.
- Common-mode choke on the pack input, mandatory for this variant
  (`TODO.md` 15.7).
- Conducted-emissions pre-compliance; the parent's result does not transfer.

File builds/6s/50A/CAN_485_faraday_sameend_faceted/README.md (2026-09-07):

# Build: 6S / 50A / CAN-FD + RS-485 / Faraday / Same-end egress / Faceted

Governed by [`AGENTS.md`](../../../../AGENTS.md). Per-build instantiation of
the axis options in the repo-root [`README.md`](../../../../README.md).

**Parent build:** [`../CAN_485_faraday_sameend/`](../CAN_485_faraday_sameend/).
This variant differs on the **Form Factor** axis (`Faceted`) and inherits the
parent's entire BOM and schematic. The BOM is deliberately **not**
duplicated here.

**Renamed 2026-09-05** from `CAN_485_faraday_faceted` to
`CAN_485_faraday_sameend_faceted`, once a second faceted build (from the
**opposite-end** parent, `../CAN_485_faraday_faceted/`) was also
instantiated. The original name did not distinguish which egress parent it
came from.

**Status: INITIAL PLACEMENT DONE. Not routed. Not fabricable.** Every
footprint is placed inside a 23.00 mm strip with zero courtyard overlaps and
zero DRC errors. No copper, no stackup, no interconnect part. AI-generated by
**Claude Opus 5** (Anthropic), 2026-09-05. Not human-reviewed.

## Requested build parameters

| Axis | Selection | Same as parent? |
| --- | --- | --- |
| Voltage / Amperage | 6S / 50A | yes |
| Protocol | CAN-FD **and** RS-485 | yes |
| EMI Hardening | Faraday | yes |
| Wire Egress | Same-end, opposite faces | yes |
| **Form Factor** | **Faceted** (two panels, placed) | **NO — this variant** |

## 1. What changed since the partition-only build

The [prior faceted build](../../../../TODO.md) (§16.4i) established the
**functional partition** — power stage on Panel P, logic/comms on Panel L,
19-net signal-only interconnect — but placed nothing. This build runs
[`docs/tools/facet_placement.py`](../../../../docs/tools/facet_placement.py)
against that same partition to produce real footprint placement.

```text
Panel P (power stage): 30 parts, 23.00 x 89.51 mm
  rotated 90 deg to fit strip width: SH1
Panel L (logic/comms):  35 parts, 23.00 x 61.68 mm
```

**SH1 fits — by rotation, not by re-selection.** The Faraday shield can
(Würth WE-SHC 3670209) is 22.75 × 17.15 mm. Un-rotated, 22.75 mm against a
23.00 mm strip left 0.25 mm total margin — not workable, per `TODO.md`
16.4e. Rotated 90°, it presents **17.15 mm** across the strip (5.85 mm of
margin) and 22.75 mm along the panel's length, which the shelf-packer
already has room for. This is placement, not a redesign: the can's PCB
footprint pads are symmetric enough that a 90° rotation does not change
which nodes it shields — but **the physical shielding geometry after
rotation has not been re-verified against the switching node it must
cover**, and that check is still open (see §4).

## 2. Panel envelopes, as placed

| | Panel P | Panel L |
| --- | --- | --- |
| Parts | 30 | 35 |
| Strip width | 23.00 mm | 23.00 mm |
| Length (component-driven) | 89.51 mm | 61.68 mm |
| Combined envelope (side by side, 3 mm gap) | 49.00 × 89.51 mm | |

**Length is the component-driven dimension**, exactly as the Form Factor
axis's `Component-Driven Dimension` column describes: width was pinned at
23.00 mm and the parts then set how long each panel had to be. Panel P is
longer than Panel L primarily because of SH1's rotated 22.75 mm run and the
six FET packages, which do not tile as densely as the smaller logic
passives.

**These lengths are a placement floor, not a routed length.** The
shelf-packer is a simple greedy row-packer (largest-area-first, no routing
awareness); it proves the parts fit and gives real numbers, but a
routing-aware placement pass will very likely produce different lengths
once track and clearance requirements shape the packing.

## 3. Verification performed

Toolchain: KiCad **9.0.2** throughout (`/usr/bin/kicad-cli`,
`pcbnew 9.0.2+dfsg-1`). Both output boards remain `version 20241229` /
`generator_version "9.0"` — not advanced to KiCad 10.

| Check | Result |
| --- | --- |
| Courtyard overlaps (all 65 parts, both panels) | **0** |
| DRC errors | **0** |
| DRC warnings | 48 (`silk_edge_clearance` 7, `silk_over_copper` 24, `silk_overlap` 17 — all silkscreen, expected on an unrouted repositioned board) |
| Unconnected items | 184 (expected — no copper exists yet) |
| Board format after write | `version 20241229` / `"9.0"` — unchanged |

## 4. What is not done

- **Routing, stackup, copper.** No track, via, or zone exists on this board
  — they were all deliberately stripped from the flat parent's geometry,
  which did not apply to this layout. `TODO.md` 15.2 (stackup) is
  unresolved and gates real copper.
- **SH1's rotated shielding geometry is unverified.** Rotating the can
  changes which board area its skirt covers relative to the switching node
  it exists to shield. This needs a real check against the gate-drive loop
  once Panel P's power-stage internals (Q1–Q6, U5) are placed relative to
  it — right now the shelf-packer places SH1 as just another rectangle by
  area, with no awareness of what it must physically enclose.
- **Interconnect part.** No connector, busbar, or flex chosen (19 signal
  nets, per the parent partition build).
- **Panel length is not routing-aware** (§2).
- **Host envelope confirmation** (`TODO.md` 16.3) — R = 30 mm and the
  2.5 mm depth budget are the owner's figures; the ~90 mm and ~62 mm panel
  lengths have not been checked against the nacelle's internal length.
- **Mounting scheme** (`TODO.md` 16.4h) — still the item that decides
  vibration survival for either faceted option, still with no owner.

## 5. Reproducing this placement

```bash
python3 docs/tools/facet_placement.py \
    --board builds/6s/50A/CAN_485_faraday_sameend/kicad/open_secure_esc_6s_50a_can485_faraday_sameend.kicad_pcb \
    --output kicad/open_secure_esc_6s_50a_can485_faraday_sameend_faceted.kicad_pcb \
    --strip-width 23.0 --gap 3.0 \
    --json kicad/placement.json
```

KiCad **9.0.2** only — see
[`docs/solutions/architecture-patterns/pcbnew-bulk-removal-segfault.md`](../../../../docs/solutions/architecture-patterns/pcbnew-bulk-removal-segfault.md)
for a pcbnew scripting trap this tool works around (bulk zone/track/drawing
removal segfaults at process exit on this binding unless handled correctly
— the tool handles it; know this before writing a similar script by hand).

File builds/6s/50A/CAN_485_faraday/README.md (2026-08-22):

# Build: 6S / 50A / CAN-FD + RS-485 / Faraday

Governed by `AGENTS.md`. This document is the per-build instantiation of the
axis options in the repo-root `README.md`, produced by walking
`docs/decision-matrix.xlsx` for each requested axis. It is the descriptive
counterpart to `kicad/` (schematic/symbols) and `gerbers/` (fab output).

## Requested build parameters

| Axis | Selection |
| --- | --- |
| Voltage | 6S |
| Amperage | 50A |
| Protocol | CAN-FD **and** RS-485 (both present simultaneously, not alternatives) |
| Control | *Not specified in this build request* — left open, see "Open items" |
| EMI Hardening | Faraday, sized against a 500 W/m² broadband RF environment |

All parts below are drawn from `docs/decision-matrix.xlsx` (generated
2026-08-02) and carry that workbook's per-row verification status. A
`Candidate (unverified)` status means the part/spec was corroborated via
≥2 independent secondary sources but this session could not open its
primary datasheet directly (every domain tried returned HTTP 403 — see
`TODO.md` 1.10); it is not yet locked into a shippable BOM. Corresponding
KiCad symbols and their own pin-map verification status are in
`symbols/README.md`.

## Bill of materials

### MCU / trust anchor (common to all builds, README.md)

> **AS-BUILT CORRECTION (2026-08-15).** This section describes the NXP
> S32K144. **The KiCad schematic in `kicad/` does not contain an S32K144.**
> U1 is a **TI MSPM0G3518-Q1, package PM (LQFP-64), orderable
> `M0G3518QPMRQ1`** — REFERENCES.md [44] — swapped in per TODO.md §13.1 and
> recorded in `kicad/sym-lib-table` ("Project MCU as of 2026-08-10;
> supersedes S32K144"). Unlike the S32K144's, its pin numbers are **VERIFIED**
> against [44] (`symbols/specs/MSPM0G3518_Q1_PM.json`), so the
> "UNVERIFIED PLACEHOLDER PIN MAP" caveat below no longer applies to the part
> actually in the design.
>
> The text below is left in place rather than rewritten, because it is
> historical BOM record for a part no longer on the schematic, not because
> the swap's documentation is still lagging. **Update 2026-08-22: TODO.md
> §13.1.e is closed** — `docs/secure-element-architecture.md` has been
> rewritten for the MSPM0's `AESADV`/Keystore (C-01 RESOLVED; the CSEc/HSRUN
> exclusion C-05 marked SUPERSEDED, with the MSPM0's own clock/crypto
> interaction explicitly flagged `UNVERIFIED` rather than assumed absent).
> **§13.1.f raised a new finding (C-08) rather than closing cleanly:** the
> keystore slot count (4 vs. CSEc's 17) was not the real problem — the real
> gap is that CSEc's runtime-loadable volatile `RAM_KEY` has no confirmed
> MSPM0 equivalent, so how a freshly ECDHE-negotiated session key reaches the
> MCU's AES engine is undesigned. See `docs/secure-element-architecture.md`
> §4 C-08 and `TODO.md` 13.1.f/13.1.i. Every "CSEc" statement below therefore
> still describes a part that is no longer in this build; read it as history,
> not as this build's current security architecture. The OPTIGA Trust M's
> justification is unaffected — the MSPM0's AES engine is still symmetric, so
> the asymmetric layer is still required.
>
> Two other things below are also now stale: `C_VCORE` is **verified at
> 470 nF, +/-20%** ([44] Recommended Operating Conditions, and "A 0.47 µF tank
> capacitor is required for the VCORE pin"), which closes TODO.md §13.1.b; and
> the LPSPI/LPI2C channel names are S32K144 peripheral names.

| Part | Qty | Citation | Status |
| --- | --- | --- | --- |
| NXP S32K144 (64-pin LQFP) | 1 | [31] | Feature-level facts verified (local datasheet); physical pin-number map is an UNVERIFIED PLACEHOLDER pending the S32K1xx Reference Manual (see `symbols/specs/S32K144.json`). Package choice (64-LQFP, one of four this device ships in) is this build's own decision — needs 1 FlexCAN-FD instance, 1 spare LPUART, 1 LPSPI (gate driver only — see below), 4 analog channels, SWD concurrently, comfortably within every S32K14x family member's minimum peripheral count. |

**2026-08-03: TPM dropped.** This build no longer includes a discrete TPM.
The Infineon SLB9672 TPM 2.0 (previously listed here, [2]) has been removed
from the design; message authentication is instead provided by the S32K144's
own on-chip CSEc (Cryptographic Services Engine) security module [31], which
implements the SHE (Secure Hardware Extension) Functional Specification's
cryptographic function set. Because CSEc has no dedicated external pins (it
is driven entirely over an internal firmware command interface), dropping
the SLB9672 also frees the LPSPI channel this build previously reserved for
TPM SPI traffic — see `symbols/specs/S32K144.json`. The algorithm-level
detail of CSEc's message-authentication function (e.g. AES-128-CMAC) is not
yet independently verified against a primary NXP/HIS source in this repo —
flagged `UNVERIFIED — needs primary source (see TODO.md)` per `AGENTS.md`
§1.3, tracked in `TODO.md` §4.

**2026-08-10: secure element added (`U2`).** The TPM stays dropped, but CSEc
alone was never a complete root of trust — it is symmetric-only, so it cannot
do public-key device authentication, key agreement with an unknown peer, or
certificate validation. An **Infineon OPTIGA™ Trust M V3** secure element
(sales code SLS 32AIA010ML, ETR −40 °C to +105 °C, PG-USON-10-2,-4,
3 mm × 3 mm / 0.118 in × 0.118 in) [45] now occupies the `U2` designator the
SLB9672 vacated and supplies exactly that asymmetric layer over LPI2C.

| Part | Qty | Citation | Status |
| --- | --- | --- | --- |
| Infineon OPTIGA™ Trust M V3 (PG-USON-10-2,-4) | 1 | [45] | Pin map VERIFIED from [45] p.17 Table 6. Footprint hand-authored for this repo; its LAND PATTERN is an IPC-7351-style derivation, **not** an Infineon recommendation — [45] publishes none. |
| 10 kΩ 0805 I²C pull-up | 2 | [45] p.12 Fig. 2 | Datasheet reference value; [45] notes the correct value depends on bus capacitance and I²C frequency — confirm before fab. |
| 100 nF 0805 VCC decoupling | 1 | [45] p.12 Fig. 2 | — |

It is a **secure element, not a TPM** — a key vault with a crypto engine,
not a platform-integrity module with PCRs and attestation. The division of
labour is deliberate and load-bearing: the Trust M establishes identity and
agrees a session key at boot; CSEc consumes that key for every frame
thereafter. The hot path **must not** call the secure element — [45] p.28
§7.2 permits only one protected operation per 5 s `t_max` period, and any use
of the fab-provisioned identity key is a protected operation.

Full rationale, the security-monitor budget, the cryptographic assessment
(including anti-replay, MAC truncation on CAN-FD, and the CSEc/HSRUN clock
exclusion), and the OT-style review are in
[`../../../../docs/secure-element-architecture.md`](../../../../docs/secure-element-architecture.md).
Several items there are **OPEN and safety-relevant** — in particular, the
behaviour on MAC verification failure is undefined and must be decided before
this build flies.

### Voltage tier — 6S

| Part | Qty | Citation | Status |
| --- | --- | --- | --- |
| Molicel INR-21700-P42A cell | 6 (series) | [14] | Candidate — datasheet VERIFIED locally 2026-08-02 (`docs/datasheets/INR21700P42A-V4-80092.pdf`), not yet locked into BOM — pack: 21.6 V nominal / 25.2 V max / 15.0 V min |
| Bulk input capacitor, V ≥ 25.2 V (≈2× margin recommended → ≥50 V rated) | TBD (generic `Device:C_Polarized`) | [14], [20], [21] | Generic part, not sourced individually — size against final layout |

### Amperage tier — 50A

| Part | Qty | Citation | Status |
| --- | --- | --- | --- |
| Infineon IRFB4110PBF power MOSFET | 6 (1 per switch position × 2 positions × 3 phases; "FET Qty/Phase Leg" = 1 at 50A) | [20] | Candidate — datasheet VERIFIED locally 2026-08-02 (`docs/datasheets/infineon-irfb4110-datasheet-en.pdf`), not yet locked into BOM |
| TI DRV8353S 3-phase gate driver (SPI variant) | 1 | [21] | Candidate — datasheet VERIFIED locally 2026-08-02 (`docs/datasheets/drv8353.pdf`), not yet locked into BOM — integrates 3 per-phase shunt-sense amplifiers itself |
| Vishay WSLP2512 shunt, 1 mΩ | 3 (one per phase; "Shunt Qty Needed" = 1 parallel device per location at 50A) | [23] | Candidate — datasheet VERIFIED locally 2026-08-02 (`docs/datasheets/wslp.pdf`), not yet locked into BOM |
| TI INA240 current-sense amp, 200 V/V gain | 3 (one per phase) — **open, see note below** | [22] | Candidate — datasheet VERIFIED locally 2026-08-02 (`docs/datasheets/ina240.pdf`), not yet locked into BOM |

**Open design question, not resolved here:** REFERENCES.md [21] states
DRV8353S already integrates 3 low-side per-phase shunt-sense amplifiers.
`docs/decision-matrix.xlsx`'s Amperage sheet nonetheless lists INA240 as a
separate BOM line for every tier. Whether this build needs external INA240
devices at all (e.g. for an MCU-independent overcurrent trip path separate
from DRV8353S's own CSA outputs) or can rely solely on DRV8353S's
integrated sensing is an open design-review question — flagged per
`AGENTS.md` §4 rather than silently picked. The MCU's `ADC_IU`/`ADC_IV`/
`ADC_IW` pins (`symbols/specs/S32K144.json`) work with either sourcing
choice.

### Protocol — CAN-FD + RS-485 (both, concurrently)

| Part | Qty | Citation | Status |
| --- | --- | --- | --- |
| Analog Devices ADM3055E **or** ADM3057E isolated CAN-FD transceiver | 1 | [6], [10] | Candidate (unverified) — **open**: ADM3055E (5000 V rms isolation) vs. ADM3057E (3750 V rms) not chosen here; pick per this build's actual isolation requirement (not specified by the request) |
| Analog Devices ADM2582E **or** ADM2587E isolated RS-485 transceiver | 1 | [4], [9] | Candidate (unverified) — **open**: ADM2582E (16 Mbps) vs. ADM2587E (500 kbps) not chosen here; pick per this build's actual RS-485 data-rate requirement (not specified by the request) |

Both protocol stacks fit on the MCU concurrently without pin conflicts: CAN
on one of the S32K144's FlexCAN instances (1 of which supports CAN-FD),
RS-485 on a spare LPUART plus one GPIO for combined DE/RE control of the
half-duplex transceiver — see `symbols/specs/S32K144.json` for the full
signal-role assignment. Note: unlike the now-superseded MSPM0G3507 spec,
which pinned each signal to a specific verified physical pin number, the
S32K144 spec's pin numbers are an UNVERIFIED PLACEHOLDER (the local S32K1xx
data sheet [31] does not contain the physical pinout table — see that
entry's "Not verified" note) — the module-level claim above (CAN-FD + spare
LPUART + GPIO fit concurrently) rests on the datasheet's verified
family-wide peripheral *counts*, not on a specific verified pin location.

### EMI Hardening — Faraday tier

| Part | Qty | Citation | Status |
| --- | --- | --- | --- |
| Würth Elektronik WE-SHC 3671375 shielding **cover** | 1 (sized to the gate-drive / high-di/dt switching-node area) | [15], [19] | Candidate — datasheet VERIFIED locally 2026-08-02 (`docs/datasheets/3671375.pdf`), mechanical part, no schematic signal pins, see `symbols/WE_SHC_3671375.kicad_sym` |
| Würth Elektronik WE-SHC 3670375 shielding **frame** (required pair to the 3671375 cover above — both datasheets' own text: "Assembly with Frame: Frame (3670375), Cover (3671375)") | 1 | [15], [19], [30] | Candidate — datasheet VERIFIED locally 2026-08-02 (`docs/datasheets/3670375.pdf`), mechanical part, no schematic signal pins, see `symbols/WE_SHC_3670375.kicad_sym` |

**Why Faraday, not a lower tier, for this environment:** the stated
requirement is a 500 W/m² broadband RF environment. Converting that power
density to an equivalent far-field RMS field strength via the standard
plane-wave relation `E_rms = sqrt(S · η₀)` (S = power density, η₀ ≈ 376.73 Ω
free-space impedance — a physical constant, not a project-specific
citation):

```text
E_rms = sqrt(500 W/m² × 376.73 Ω) ≈ 434 V/m
```

That is well above the field strengths conventionally mitigated by
grounding/layout practice alone, and above typical MIL-STD-461G RS103
radiated-susceptibility test limits for most platform categories (commonly
≤200 V/m; only the most severe avionics zones reach 400-800 V/m) — see
[15]'s RE102/CE102 shielding-effectiveness rationale, cited in the
`docs/decision-matrix.xlsx` EMI Hardening sheet for exactly this tier. This
places the requirement in board-level shielding-can territory rather than
the Isolation or Grounding tiers, hence Faraday. This derivation is an
engineering calculation applying a standard electromagnetics identity, not
itself a standards citation — flagged as a judgment call per `AGENTS.md` §4.
The requirement is framed as *broadband*, i.e. a radiated-susceptibility
scenario; it does not by itself specify conducted-immunity limits (MIL-STD-
461G CS101/CS114/CS115/CS116) — those remain open per the Grounding tier's
existing layout guidance ([15], [17]) already in the base decision matrix.

### Parts added by the 2026-08-15 layout pass

| Part | Ref | Qty | Citation | Status |
| --- | --- | --- | --- | --- |
| 10 kΩ 0805 pull-up on the gate driver's SDO line | R14 | 1 | [21] | **Required by the datasheet, was missing.** [21]'s "Pin Functions — 40-Pin DRV8353 Devices" gives SDO (pin 27) as type **OD** and states "This pin requires an external pullup resistor." Without it no SPI register read from the gate driver can work. The 10 kΩ *value* is an engineering default matched to R11 (nFAULT, the other open-drain pin); [21] specifies no value. |
| Pack input terminal, 6 mm² solder-wire pads | J5 | 1 | — | **Engineering default, not a selected part.** VM previously had no connector of any kind, so the board could not be energised (BT1–BT6 are an off-board assembly). Sized as the largest pad in KiCad's stock library, not against a current rating. See TODO.md §12.4.k/§12.4.l. |
| Motor phase terminal, 6 mm² solder-wire pads | J4 | 1 | — | **Footprint changed 2026-08-15**, was a 2.54 mm pin header — not a 50 A part. Same engineering-default caveat as J5. |

Conductor sizing for all of the above is governed by IPC-2152 [46], whose body
is paywalled and has **not** been read; only its Table of Contents is verified.
No width, plane cross-section or pad in this build is an IPC-2152 result.

## Open items (not resolved in this document)

- Control-loop topology (Open / Closed-Diff / Closed-PID) — not specified
  in the build request; see `docs/decision-matrix.xlsx` Control sheet.
- CAN-FD transceiver variant (ADM3055E vs. ADM3057E) and RS-485 transceiver
  variant (ADM2582E vs. ADM2587E) — isolation-voltage / data-rate tradeoff,
  not specified in the build request.
- DRV8353S vs. external INA240 current-sense sourcing (see BOM note above)
  — a design-review question, unaffected by DRV8353S's datasheet now
  being verified.
- **Every part in this build's BOM now has a locally verified primary
  datasheet** — the last two gaps (TI DRV8353S [21] and the WE-SHC
  3670375 frame [30]) were closed 2026-08-02. Two earlier lookalike PDFs
  (`docs/datasheets/wsl.pdf`, `docs/datasheets/3690103020.pdf`) had not
  resolved these gaps — see [24]/[25] in `REFERENCES.md` for why (wrong
  Vishay family, and a shield at the wrong physical scale) — the actual
  correct documents (`docs/datasheets/drv8353.pdf`, `.../3670375.pdf`)
  were added separately and confirmed to match.
- None of this means the BOM is "settled" per `AGENTS.md` §5 — every
  line is still "Candidate" in the sense that no part has been formally
  locked in, and several open design questions above (control-loop
  topology, transceiver variants, DRV8353S-vs-INA240 sourcing) remain
  genuinely unresolved. Datasheet verification and BOM lock-in are two
  different gates.
- Four alternative-manufacturer datasheets were also added 2026-08-02
  (Molicel P45B, Samsung SDI 40T, Analog Devices AD8410A, Infineon
  TLE9180D-31QK — see `REFERENCES.md` [26]-[29]) but none is adopted
  into this BOM; they're reference material for the open design
  questions above. **The Samsung 40T datasheet is marked "Confidential
  Proprietary" by Samsung on every page** — flagged in [27] for the
  repo owner to decide whether it belongs in a shared/public repo at
  all, independent of its technical accuracy.

## Folder contents

- `README.md` — this file.
- `kicad/` — populated KiCad project: schematic (all BOM parts below placed
  and wired), `.kicad_pro`, and a PCB with footprints placed and a board
  outline (not yet routed). Title block company: **Griffing Technology
  LLC**. See `kicad/README.md` for exact status, including what's still
  open (no footprint for the DRV8353S gate driver, no netlist/routing yet,
  and the open design questions noted in this document are deliberately
  left open there too, not silently resolved).
- `gerbers/` — fabrication output; still empty, the PCB isn't routed yet,
  see `gerbers/README.md`.

Symbols referenced by this build live in the repo-root `symbols/` library,
shared across all builds — see `symbols/README.md` for citation/
verification status per component and the workflow for adding more.

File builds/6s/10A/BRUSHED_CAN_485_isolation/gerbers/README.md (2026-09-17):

# gerbers/ — 6S / 10A / BRUSHED / CAN-FD+RS-485 / Isolation

Empty, and deliberately so. This build is at **schematic + BOM readiness**
(`../kicad/README.md`): the schematic is ERC-clean and its netlist has been
verified, but no PCB has been placed or routed. Gerbers are generated only
after the layout follow-up (`TODO.md` 18.6) closes:

1. Buck inductors and catch diodes selected against the 4 mm height budget
   and their datasheets held locally (`TODO.md` 18.3).
2. Placement inside the 42.9 × 36.5 mm host envelope with the isolated rows
   on the long axis and the primary side clear of the barrier
   (`docs/tools/isolation_envelope.py` result in `../kicad/README.md`).
3. Conductor sizing for the 3 A branch / 2.9 A motor stall
   (`docs/tools/conductor_sizing.py`; IPC-2152 [46] is still paywalled, so no
   width may be presented as computed until it is read).
4. DRC clean at `--severity-error`, including the isolation-barrier via rule
   in the `.kicad_dru` and its negative control.

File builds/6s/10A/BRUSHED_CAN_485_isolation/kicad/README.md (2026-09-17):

# kicad/ — 6S / 10A / BRUSHED / CAN-FD+RS-485 / Isolation

Governed by `AGENTS.md`. Build spec: `../README.md`. Plan: Serenity-UAV
`docs/plans/2026-09-17-001-feat-tilt-controller-open-secure-esc-build-plan.md` (U4).

## Status

| Item | State (2026-09-17) |
| --- | --- |
| Schematic | Generated by `tools/gen_schematic.py`; **ERC 0 errors / 0 warnings** at `--severity-all` (kicad-cli 9.0.2, project context) |
| Netlist | 90 nets, 81 parts; every intended net present, no single-pin nets, PMODE → GND, IMODE strap, nFAULT pull-up, BRAKE_EN pull-down and VM-sense divider all confirmed from `kicad-cli sch export netlist` |
| PCB | Not started — no `.kicad_pcb`; see `../gerbers/README.md` for the gate list |
| Envelope check | `docs/tools/isolation_envelope.py --widest 7.0 --board-width 36.5` → minimum width 25.96 mm for the widest non-isolated part (a 7 mm inductor class) to sit between the two isolated rows; at 36.5 mm the check passes with 12.8 mm of margin, so control sits alongside comms with no creepage band in the stack |

## How the sheet is built (read before editing)

The schematic is **label-wired, not drawn**: every pin that carries a net has
a global label placed on its connection point and every unused pin has a
no-connect flag there. There are no wires. This is deliberate — it removes
the hand-wiring Y-sign trap (`docs/solutions/architecture-patterns/schematic-pin-y-sign-when-hand-wiring.md`)
and makes the netlist the proof of connectivity. The consequence is that the
sheet is a netlist you can open in KiCad, not a diagram arranged for
reading; a human-arranged view is a follow-up (`TODO.md` 18.6).

`tools/gen_schematic.py` is the single source. It reads pin geometry from the
same `symbols/*.kicad_sym` files it embeds, so a regenerated symbol cannot
drift from the sheet. `python3 tools/gen_schematic.py --check` exits 0 only
when the committed sheet equals the generator output — run it before every
commit that touches either. **Do not edit the `.kicad_sch` by hand**; if
KiCad's GUI is used to rearrange it, port the change into the generator
or the next regeneration will drop it (the 6S/50A build's divergence trap).

## Files

| File | What it is |
| --- | --- |
| `open_secure_esc_6s_10a_brushed_can485_iso.kicad_sch` | The schematic (KiCad 9 format 20250114), generated |
| `open_secure_esc_6s_10a_brushed_can485_iso.kicad_pro` | Project file: net classes Default / Power (1.5 mm) / Motor (1.5 mm) / Isolated / Sense with the net assignments below |
| `open_secure_esc_6s_10a_brushed_can485_iso.kicad_dru` | Custom rules: power/motor/sense conductor spacing, isolation-barrier no-via rule (7.5 mm, [9] Table 6) with its negative control |
| `sym-lib-table` | Symbol bindings to `symbols/`, each `descr` carrying the REFERENCES tag and verification note |
| `fp-lib-table` | `Open_Secure_ESC.pretty` (this repo's TI PWP0016J / DDA0008B / OPTIGA USON-10 footprints) |
| `tools/gen_schematic.py` | Generator (kiutils-free) |

## Net classes

| Class | Nets | Why |
| --- | --- | --- |
| Power | VBAT, GND, VMOT, 3V3, U6_SW, U8_SW | 3 A branch, 2.9 A motor stall; width sized in the layout follow-up (IPC-2152 [46] unread) |
| Motor | MOT_OUT1, MOT_OUT2, SOL_N | Bridge outputs and the solenoid sink |
| Isolated | CAN_H/L, CAN_VISOIN/OUT, CAN_ISO_GND, CAN_GNDISO, RS485_A/B, RS485_VISOIN/OUT, RS485_ISO_GND, RS485_GNDISO | Isolated side of both transceivers; the `.kicad_dru` via rule keys on this class |
| Sense | ADC_IPROPI, ADC_VM, ADC_VBUS, BRAKE_SENSE, U5_VREF, U5_IPROPI | Analog, 0.3 mm spacing |

## Libraries (sym-lib-table)

| Nickname | Symbol | Pin-map status |
| --- | --- | --- |
| `MSPM0G3518_Q1_RHB_TILT` | U1 MCU, tilt-build role names, all 32 pins | VERIFIED — [44] Fig. 6-6 / Table 6-2 (`symbols/specs/MSPM0G3518_Q1_RHB_TILT.json`) |
| `OPTIGA_TRUST_M` | U2 | VERIFIED — [45] p.17 Table 6 |
| `ADM3055E_ADM3057E` | U3 (ADM3057E) | VERIFIED — [10]; part Candidate |
| `ADM2582E_ADM2587E` | U4 (ADM2587E) | VERIFIED — [9]; part Candidate |
| `DRV8874_Q1` | U5 | VERIFIED — [63] §5, cross-checked [62] |
| `TPS54560B` | U6, U8 | VERIFIED — [65] §5 |
| `TPL7407L` | U7 | VERIFIED — [66] §5 |
| `BLM15HD182SN1D` | FB1–FB4 | VERIFIED — [53] |
| `AEAT_8800_Q24` | (not placed; off-board sensor daughter) | VERIFIED — [64] |
| `Open_Secure_ESC_Generic` | R, C, Conn_01x02/04, PWR_FLAG | Generic |
| `Device`, `Connector_Generic` (KiCad stock) | L1/L2, D1/D2, J7 | Generic; parts UNVERIFIED — see `../README.md` |

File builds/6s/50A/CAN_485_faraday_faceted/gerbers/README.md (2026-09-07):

# Gerbers — 6S / 50A / CAN-FD + RS-485 / Faraday / Opposite-end egress / Faceted

**Empty by design.** Placement is done; routing, stackup, and interconnect
selection are not. See [`../README.md`](../README.md) §4.

Generate with KiCad **9.0.2** only.

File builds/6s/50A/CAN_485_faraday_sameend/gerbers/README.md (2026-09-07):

# Gerbers — 6S / 50A / CAN-FD + RS-485 / Faraday / Same-end egress

**Empty by design.** No fabrication output has been generated for this build.

Three gates stand before gerbers are meaningful, all recorded in
[`../README.md`](../README.md):

1. **No stackup** — layer count, copper weight, dielectric heights and
   surface finish are unspecified (`TODO.md` 15.2). Gerbers without a stackup
   cannot be quoted or built.
2. **VM distribution unresolved** — `J5A` (VM) and `J5B` (GND) are
   unconnected at the new terminal end, pending the `TODO.md` 12.5.ae
   rule-area decision.
3. **Routing incomplete** — 150 unconnected items, inherited from the parent
   build.

Generate with KiCad **9.0.2** only. The board file is `version 20241229` /
`generator_version "9.0"`; running KiCad 10 against it would advance the
format.

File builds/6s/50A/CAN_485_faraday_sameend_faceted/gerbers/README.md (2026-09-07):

# Gerbers — 6S / 50A / CAN-FD + RS-485 / Faraday / Faceted

**Empty by design.** There are no board files yet, let alone fabrication
output. This build is partitioned, not placed — see [`../README.md`](../README.md).

Two panels will eventually be fabricated separately. Before either can be:

1. **Placement** — no parts are placed (`TODO.md` 16.5). The FET bridge must
   go from 3x2 (26.96 mm across) to 2x3 to fit the 23.98 mm strip.
2. **`SH1` width** — 22.75 mm against a 23.98 mm strip leaves 0.6 mm per
   edge, which is not a workable margin (`TODO.md` 16.4e).
3. **Stackup** — still undefined (`TODO.md` 15.2).
4. **Interconnect part** — no connector, busbar or flex selected.
5. **Host envelope** — unconfirmed (`TODO.md` 16.3).

Generate with KiCad **9.0.2** only.

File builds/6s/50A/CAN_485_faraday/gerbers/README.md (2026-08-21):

# gerbers/ — 6S / 50A / CAN-FD+RS-485 / Faraday

Still empty, and deliberately so.

## What changed 2026-08-15

Two of the three conditions this folder was waiting on are now met:
`../kicad/open_secure_esc_6s_50a_can485_faraday.kicad_pcb` **has** its netlist
(44 footprints, 73 nets, every pad netted from the schematic), and it **is**
routed, with poured planes on all four layers. The schematic is ERC-clean at
0 errors. See `../kicad/README.md`.

## Why gerbers are still not generated

**Conductor sizing has not been verified.** IPC-2152 [46] is the governing
standard for current-carrying capacity; it is paywalled, and only its Table of
Contents has been read, so under `AGENTS.md` §1.3 no width on this board may be
presented as a computed value. `VM` and `GND` are poured planes and the three
phase nets now have their own pours over each half-bridge, but the run from
each phase pour out to the motor terminal is still routed track, and that is
load-bearing at 50 A. Exporting fab output now would ship a board whose
headline rating — 50 A — is the one number nobody has checked.

Also still open, per `TODO.md` §12.4:

- **No real power connector has been selected.** `J4` and `J5` are KiCad
  6 mm² solder-wire pads, chosen because the previous `J4` was a 2.54 mm pin
  header. No part number, no verified current rating.
- **The BOM is not locked.** Every line in `../README.md` is still
  `Candidate` per `AGENTS.md` §5, and three design questions are genuinely
  unresolved: the CAN-FD and RS-485 transceiver variants, and
  DRV8353S-vs-INA240 current-sense sourcing. The transceiver choice also sets
  the isolation barrier width, which the layout currently sizes only to clear
  the isolated pin rows.
- **Placement has not had a human review.** It is DRC-clean and respects
  REFERENCES.md [21] §11.1's gate-loop and bulk-capacitor constraints, but
  thermal and manufacturability review of the power stage has not been done.

Datasheet verification and BOM lock-in are two different gates
(`../README.md`, "Open items"). Every part here has a verified datasheet; none
is locked.

## When those close

Export the standard fab set — `*.gbr` per copper/mask/silk/edge layer, `*.drl`
drill files, and a `*.gbrjob` — with `kicad-cli pcb export gerbers` and
`... export drill`, or `Plot` in the PCB Editor. Then update this file with the
KiCad version and the exact export settings used, per `AGENTS.md` §4: record
*why* those settings, not just *what* was exported. Copper weight in
particular is a decision that follows from the IPC-2152 work above and must be
stated here, not left to the fab's default.

Tracked in `TODO.md` §12.4.k / §12.4.l (blocking), then §10.2 (BOM
finalization) → §10.3 (manufacturing/fab release).

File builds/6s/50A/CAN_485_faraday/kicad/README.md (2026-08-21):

# kicad/ — 6S / 50A / CAN-FD+RS-485 / Faraday

Governed by `AGENTS.md`. Open items are tracked in the repo-root `TODO.md`
§12.4; this file describes what the two design files currently contain.

## Status

**Schematic: ERC-clean (0 errors). PCB: placement and pour work advanced
2026-08-19/20; the board is deliberately committed UNROUTED.** The previous
route was invalidated by the shield-ring part moves and was cleared rather than
committed, because a stale route shorts nets. Regenerate with
`tools/autoroute.py` then `tools/stitch_planes.py`.

Current DRC: **20 violations — 11 `silk_over_copper`, 7 `silk_overlap`,
2 `isolated_copper`. Zero shorts, zero clearance, zero isolation violations.**
151 unconnected (i.e. unrouted). Not fabrication-ready.

| | State |
| --- | --- |
| Schematic | 50 parts, annotated, **0 ERC errors** (`endpoint_off_grid` + `global_label_dangling` warnings remain — see below) |
| PCB | **32.0 × 66.1 mm**, double-sided, 65 footprints, 75 nets, 4 layers, planes poured and stitched, isolation rule area (**stranded — `TODO.md` 12.5.z**). **0 courtyard overlaps, 0 clearance errors, 0 hole-clearance errors** |
| Routing | **Cleared 2026-08-20** — see "Routing" below. Regenerate with `tools/autoroute.py`, then `tools/stitch_planes.py` |
| Gerbers | Not generated. See "Before you fabricate". |

### Placement history

The respin was drawn for a 30 × 60 mm envelope and `tools/build_pcb.py` still
writes that placement. The repo owner then hand-placed the board, after which
it narrowed to **25.4 × 60.1 mm (1 inch wide)** without shrinking any phase
pour — the inch came from dead margin between the FET columns, not from
copper. See the commit "Narrow the board to 25.4 mm" for the full accounting.

`BT1`–`BT6` (the 21700 cells) and `SH2` (the shield cover) are in the BOM but
marked *exclude from board*.

### Respin BOM changes (2026-08-15/16)

| Was | Now | Why |
| --- | --- | --- |
| IRFB4110PBF, TO-220AB THT | **TPHR8504PL**, 2-5W1A SOP Advance(N) | 5.7× lower conduction loss; SMD enables double-sided. Voltage margin drops 3.97× → 1.59× — bound the overshoot before fab |
| WE-SHC 3670375/3671375 | **3670209/3671209** | 812 mm² saved |
| 1 mΩ shunts | **0.5 mΩ** | 2.5 W → 1.25 W against a 3.0 W part |
| C1 10 mm radial | **1210 SMD** | Envelope; holds far less bulk — see its Note |
| J4 3-pin, J5 2-pin | **J4A/B/C, J5A/B** | Terminals fit across the 30 mm width |
| J1–J4 THT headers | **SMD solder pads** | A THT part blocks both sides; 9 of them cost 964 mm² of a 3600 mm² budget |

## Files

| File | What it is |
| --- | --- |
| `*.kicad_sch` | Single sheet, A0. Title block company **Griffing Technology LLC**. |
| `*.kicad_pcb` | 25.4 × 60.1 mm, 4 layers, double-sided, rounded corners. |
| `*.kicad_pro` | Project settings. **Net classes live here**, not in the board. |
| `sym-lib-table`, `fp-lib-table` | Project-relative tables pointing at the shared `symbols/` library. |
| `tools/` | Generators. Re-run these rather than hand-editing the generated files. |

## The board

**4 layers.** Two layers cannot carry this build's currents, and the ground
planes are also the layout half of the Faraday EMI tier — a shield can only
helps if the return currents underneath it are not already radiating.

```text
F.Cu    components, signal routing, per-phase pours over each half-bridge
In1.Cu  GND plane, solid, full board
In2.Cu  VM plane over the power stage, GND under the control section
B.Cu    signal routing, GND pour
```

**Placement** follows the signal flow, and the power stage follows
REFERENCES.md [21] §11.1 "Layout Guidelines" — bulk capacitance positioned to
minimise the high-current loop through the external MOSFETs, and minimised
high-side and low-side gate loops:

- **Top band** — pack input (`J5`), bulk cap (`C1`), the three half-bridges
  (`Q1`/`Q2`, `Q3`/`Q4`, `Q5`/`Q6`), the three low-side shunts (`R1`–`R3`),
  and the phase terminal (`J4`) at the right edge.
- **Below the shunts** — the three INA240 current-sense amplifiers
  (`U6`–`U8`), each directly under its own shunt.
- **Middle** — `U5` (gate driver) and its five support capacitors, all
  *inside* the WE-SHC shield frame (`SH1`). The frame's courtyard is an
  annulus, so enclosing parts is not a DRC error.
- **Bottom left** — `U1` (MCU), `U2` (OPTIGA Trust M), decoupling, pull-ups,
  and `J1` (SWD), furthest from the switching node.
- **Bottom right** — the two isolated transceivers (`U3` CAN-FD, `U4`
  RS-485), each rotated so its **isolated pin row faces the board edge**, with
  `J2`/`J3` beyond them. A **copper keepout** removes every plane and pour
  from that band: without it the GND plane runs straight under the isolation
  barrier, which defeats the isolator.

## What the 2026-08-15 pass fixed

This folder previously held a schematic with no reference designators and a
PCB where, in the words of this file's earlier revision, "every PCB pad is
net-less (`net 0`); footprints are placed for board-planning legibility only."
Four of the fixes were real electrical defects, not tidying:

1. **The gate driver's SPI read path had no pull-up.** REFERENCES.md [21]
   lists `SDO` (pin 27) as type **OD** and states "This pin requires an
   external pullup resistor." There was none, so no SPI register read from the
   DRV8353S could have worked. `R14` (10 kΩ to 3V3) added, mirroring `R11` on
   `nFAULT`, the other open-drain pin.
2. **The board had no battery input.** `VM` reached `C1`, `C6`, `R8`, `U5` and
   three MOSFET drains — and no connector. The previous PCB had a `J5`
   footprint with *no schematic counterpart*, i.e. two netless pads. `J5` is
   now a real schematic part on `VM`/`GND`.
3. **Four isolated-side power flags never reached their rails.** `#FLG04`–
   `#FLG07` were wired with long L-routes whose vertical legs stopped at the
   right Y but at x = 381.5 while the target pins sit at x = 380.01 — so not
   one of the four connected. That was 4 `power_pin_not_driven` errors on the
   transceivers' isolated supplies.
4. **The gate driver's exposed thermal pad had no electrical existence.** The
   symbol had no pin 41, so the footprint's thermal pad would have imported
   with no net — an isolated copper island directly under the power stage.

Also: all 57 symbols annotated; the 8 `PWR_FLAG`s made virtual (they had been
ordinary in-BOM parts); `U5`'s footprint authored from TI's own land pattern;
`SH1`'s authored from Würth's; the phase connector moved off a 2.54 mm pin
header; and the 32 `lib_symbol_mismatch` warnings cleared.

## Warnings that remain, and why

**350 × `endpoint_off_grid` (schematic).** `tools/genlib.py` lays the sheet out
on a 10 mm grid, which is not a multiple of KiCad's 1.27 mm connection grid.
Nothing is electrically wrong — KiCad connects by exact coordinate match — but
hand-editing the sheet in Eeschema is awkward because a wire drawn on-grid
will not land on a pin.

**Do not "fix" this with a coordinate snap.** It was tried and reverted:
`genlib.py` separates parallel routes by 0.01–0.02 mm lane offsets, and
snapping to 1.27 mm merges them. The attempt shorted VM to GND, merged all six
PWM lines into one net, shorted `CPH` to `CPL` across the charge-pump
capacitor, and collapsed 73 nets to 63. `tools/snap_to_grid.py` now refuses to
run without `--force` and documents the whole result. A real fix means
re-laying out the drawing with ≥ 1.27 mm lane spacing.

**2 × `global_label_dangling`** on `CAN_VISOOUT` and `RS485_VISOOUT`. These are
deliberate: the transceivers' isolated-supply sourcing depends on the
still-open ADM3055E-vs-ADM3057E and ADM2582E-vs-ADM2587E variant choices
(see `../README.md`), so the nets are labelled and left open rather than
resolved by the layout.

**`silk_over_copper` and `starved_thermal` (PCB).** Cosmetic and
fab-preference respectively; neither is electrical.

## Placement guide (25.4 × 60.1 mm, hand-placed)

The board is placed. This section is the record of **why** it is placed the
way it is, so a later edit does not undo a constraint by accident.

**Re-running `tools/build_pcb.py` discards the hand placement.** It rebuilds
the board from the netlist every time, from a `PLACEMENT` table that still
describes the old 30 × 60 layout. Do not run it against the committed board
without folding the current positions back into it first.

### RESOLVED — the `U5` thermal-via short

Earlier revisions of this file recorded a **verified GND-to-VM short**:
`U5`'s 12 GND thermal vias landed inside `Q3`'s `VM`, `PH_B` and gate pads.
The hand placement cleared it. Re-verified against the board 2026-08-16 —
**no `U5` thermal via intersects any pad of any other footprint**, and DRC
reports 0 clearance and 0 hole-clearance errors.

This remains the trap to re-check after **any** move of `U5` or of a `Q`.
`U5` sits on the bottom directly beneath the top-side FETs, so its via field
is always one small move away from a FET drain pad. [21]'s RTA0040B sheet
note 5 makes the vias optional ("vias are optional depending on application"),
so deleting them is a legitimate fallback if a future move re-creates the
conflict.

### Copper weight: 2 oz outer minimum, decided by calculation

`docs/tools/conductor_sizing.py` derives this from copper's resistivity --
run it, it prints the table. At 50 A through a 7.5 x 22 mm phase pour:

| Copper | R per phase | Drop | Dissipation, all 3 phases |
| --- | --- | --- | --- |
| 1 oz | 1.78 mΩ | 89 mV | **13.3 W** |
| 2 oz | 0.89 mΩ | 44 mV | 6.7 W |
| 3 oz | 0.59 mΩ | 30 mV | 4.4 W |

The six TPHR8504PL FETs dissipate 10.5 W of conduction loss between them. **At
1 oz the phase pours alone dissipate more than the FETs do** -- the copper
becomes the dominant heat source, which is indefensible on a board whose
reference design [47] already measures 103 °C at this current. 2 oz outer is
the floor; 2 oz inner as well if the budget allows, since In1/In2 carry the
GND and VM planes.

This is an engineering derivation from material constants, flagged per
`AGENTS.md` §4 -- **not** an IPC-2152 [46] result. It gives watts, not degrees.

### Keep each phase terminal on the SAME side as its pour

A phase changing layers needs **~23 × 0.3 mm vias** to present as much copper
as the 2 oz pour it continues (2.2 A per via at that count). Keeping `J4A/B/C`
on the top side, with the phase pours, costs zero vias and zero extra
dissipation. The current placement has them on the bottom -- move them up, or
budget the via field.

### Commutation loop inductance -- the number that decides the FET choice

The TPHR8504PL is a 40 V part on a 25.2 V pack. Overshoot is
`V_DS = 25.2 + L_loop x dI/dt`, and dI/dt follows the DRV8353S IDRIVE setting
(SPI-programmable 50-1000 mA, [21]; TPHR8504PL Q_SW = 23 nC, [49]):

| IDRIVE | dI/dt | L=2 nH | L=5 nH | L=10 nH | L=20 nH |
| --- | --- | --- | --- | --- | --- |
| 150 mA | 326 A/µs | 25.9 V | 26.8 V | 28.5 V | 31.7 V |
| 300 mA | 652 A/µs | 26.5 V | 28.5 V | 31.7 V | 38.2 V |
| 600 mA | 1304 A/µs | 27.8 V | 31.7 V | 38.2 V | **51.3 V** |
| 1000 mA | 2174 A/µs | 29.5 V | 36.1 V | **46.9 V** | **68.7 V** |

Bold exceeds the 40 V rating. **Loop inductance decides this, not IDRIVE.**
A 2-5 nH loop survives the fastest gate drive; a 20 nH loop breaches 40 V at
almost any useful setting. So while placing:

- Put the high-side and low-side FET of each phase **as close as the package
  allows**, drain-to-source, in the same column.
- Get the bulk capacitor into that loop, not off beside the pack terminals --
  the loop is C1 -> Q(high) -> Q(low) -> shunt -> back to C1.
- Use the In1 GND plane as the return directly beneath the loop; every mm of
  detour is inductance.
- Add local high-frequency ceramics right at each half-bridge if the bulk cap
  cannot be close to all three.

Then set IDRIVE as fast as a **bench measurement** of V_DS allows. Do not pick
it from this table -- the table shows which loop inductances are survivable,
not what your loop actually is.

### Do not move these -- they are the reason the layout works

| Group | Constraint | Why |
| --- | --- | --- |
| `Q1`/`Q2`, `Q3`/`Q4`, `Q5`/`Q6` | Keep each half-bridge in its own column, high-side above low-side | Each column is a phase pour; splitting a bridge across columns breaks the pour and lengthens the switching loop |
| `SH1` + `U5` + `C5`-`C9` | Keep the shield block on the BOTTOM, directly under the FETs | Shortest GHx->gate->SHx loop ([21] Sec. 11.1). A top-side column measured 64.7 mm against a 60 mm board -- the shield is the 17.2 mm that did not fit |
| `U6`/`U7`/`U8` | Keep each sense amp under its own shunt | Keeps the differential shunt taps short and matched between phases |
| `U3`, `U4`, `J2`, `J3` | Keep together, past the isolation keepout, away from `U1` | The keepout removes all plane copper under the barrier; parts must stay on their correct side of it |
| `C1` | Keep in the FET loop, not off by the pack pads | [21] Sec. 11.1 asks for bulk positioned to minimise the high-current loop through the MOSFETs |
| Phase pours | One per column, higher priority than the GND pour | The phase nets have no plane; the pour is their conductor |

## Routing

### 2026-08-19 routing pass — read this before re-running the router

The board reached this pass **fully unrouted**: 0 track segments, 0 vias, 157
ratsnest connections. Getting it to route surfaced ten defects, none of them
routing defects. The full write-up is
`docs/solutions/architecture-patterns/what-the-autorouter-is-never-told.md`;
the WBS is `TODO.md` 12.5.av–az. The short version:

- The project net classes had gone missing, so the 50 A pack and all three
  phases would have routed at the 0.2 mm signal default. `autoroute.py` now
  hard-stops rather than routing a board whose classes are not in effect.
- KiCad exports every rule area as a **total** Specctra keepout, losing
  `tracks allowed`. That put U1, U2 and J1 inside a no-route band; the MCU was
  unroutable and it read as congestion.
- KiCad exports In1.Cu and In2.Cu as `(type signal)`. The first run cut
  **415 mm of signal through the GND and VM planes.** They are now marked
  `(type power)`; verified 0 segments on both.
- The board had **zero vias** — all four poured planes were floating.
  `tools/stitch_planes.py` now ties them.
- The PH_A and PH_C pours had been left 3.04 mm short of the high-side FET
  source pads by an earlier alignment pass, splitting each half-bridge switch
  node. `tools/fix_phase_pours.py` re-derives them.
- **Do not turn on `--inset-boundary`.** It hung the router twice for a full
  time limit each; the pours reach the board edge and cannot live outside an
  inset boundary. See `TODO.md` 12.5.av(h).

Current state: **423 segments (287 B.Cu, 136 F.Cu, 0 on the inner planes),
125 vias, 66 open connections.** Routed track on the plane nets totals 1.3 mm
on GND and 2.0 mm on VM — that audit exists because the Power class is relaxed
to 0.5 mm in the DSN so the router can reach U5's 0.25 mm WQFN pads, and it
confirms nothing signal-width ended up in series with a 50 A conductor.

Almost every one of the 66 open connections terminates on U1 (LQFP-64) or U5
(WQFN-40). Those need a staggered dogbone fanout before another router run
will help — `TODO.md` 12.5.ay.

### Historical: the 2026-08-16 pass

`tools/autoroute.py` was run 2026-08-16 (FreeRouting 2.2.4, 100 passes,
15 min 26 s). It took the board from 124 unrouted connections to 56, laying
381 segments and 48 vias.

**Then 29 of those segments were deleted on purpose.** The router had closed
`VM` with 3.0 mm track from the "power" net class — the 5.2 W outcome
described below. `tools/strip_high_current_tracks.py` removed them and refilled
the zones, and `tools/add_vm_top_pour.py` replaced them with copper. The
router did **not** attempt the three phase nets; those connections were left
open and still are.

State at the end of that pass (superseded by the 2026-08-19 pass above):
**352 segments, 48 vias, 57 open connections.** Of those 57:

| | Count | Status |
| --- | --- | --- |
| Phase nets to their terminals | 3 | **Blocked** — needs a placement decision, see below |
| Phase nets to `U5` sense pins | 3 | Low current; routable |
| `VM` bottom-side taps (`U5`, `R8`, `C6`) | 4 | Low current (gate-driver supply, sense divider, decoupling); routable |
| `GND` stitches | 9 | Short pour-to-pad; routable |
| Ordinary signal nets | 38 | Router did not converge; re-run with more passes or route by hand |

DRC at the end of that pass: 32 `silk_over_copper`, 21 `silk_overlap`,
12 `starved_thermal`, 5 `isolated_copper`, 2 `silk_edge_clearance`.

**Current DRC (2026-08-19, after routing and stitching): 31 violations —
11 `copper_edge_clearance`, 8 `silk_over_copper`, 7 `silk_overlap`,
5 `starved_thermal`. Zero shorts, zero clearance, zero hole-clearance, zero
schematic-parity errors.** `isolated_copper` cleared when the planes were
stitched. Edge clearance is `TODO.md` 12.5.az; silkscreen is deferred
(`TODO.md` 12.5.u).

**Fab-capability note:** `U5`'s 12 thermal vias are **0.20 mm** drill. That
matches this board's own minimum (`m_MinThroughDrill` = 0.2 mm) so it is not a
rule violation, but it is below the 0.3 mm many fabs treat as standard and
will be an upcharge or a redesign at some vendors. Confirm before ordering.

### THE HIGH-CURRENT GAPS — the open electrical problem in the layout

Of the 124 unrouted connections KiCad reports, **14 are on the 50 A nets**
(`VM` 8, `PH_A`/`PH_B`/`PH_C` 2 each). Those 14 are the ones an autorouter
must not be allowed to close, because `tools/autoroute.py` puts them in a
3.0 mm "power" class — a sane width for a signal-class power net, not for
50 A. The other 110 are ordinary signal nets and are the router's job.

#### Gap 1 — `VM` has no top-side copper at all

The `VM` plane is on **In2.Cu only**. Every part that actually carries pack
current sits on **F.Cu**: `J5A` (pack +), `C1` (bulk), and the three
high-side drains `Q1`/`Q3`/`Q5`. Nothing joins them — not to each other, and
not down to the plane. KiCad's own connectivity confirms it:

```text
PTH pad 1 [VM] of J5A   <-> Pad 6 [VM] of Q1 on F.Cu
Pad 5  [VM] of Q1 on F.Cu <-> Pad 8 [VM] of Q3 on F.Cu
Pad 5  [VM] of Q3 on F.Cu <-> Pad 8 [VM] of Q5 on F.Cu
Pad 8  [VM] of Q3 on F.Cu <-> Pad 1 [VM] of C1 on F.Cu
```

The top-side `VM` pads span **x 2.20 → 22.81, y 4.60 → 13.05 mm**, so a single
F.Cu `VM` pour of roughly **22.6 × 10.5 mm** reaches all of them, and stitches
to the In2 plane wherever there is room. Worst-case lateral run is `J5A` to
the far `Q5` drain, ≈ 20.6 mm; at 2 oz:

| Conductor | R | Dissipation |
| --- | --- | --- |
| 3.0 mm track (what the router draws) | 2.08 mΩ | **5.2 W** |
| 6.0 mm | 1.04 mΩ | 2.6 W |
| 10.0 mm | 0.62 mΩ | 1.6 W |
| Full 22.6 mm pour | 0.28 mΩ | 0.7 W |

**Fix: pour `VM` on F.Cu across the top band.** It costs nothing in area — the
band is already reserved for the pack input and the high-side drains — and it
takes the run from 5.2 W to 0.7 W.

#### Gap 2 — the phase nets do not reach their own terminals

Measured off the board 2026-08-16:

| | Layer | Extent |
| --- | --- | --- |
| `PH_A`/`PH_B`/`PH_C` pours | **F.Cu** | y 11.10 → **33.10** mm |
| `J4A`/`J4B`/`J4C` pads | **B.Cu** | y **48.10** → 58.10 mm |

So each phase has a **15 mm gap and a layer change** between the pour that
carries it and the terminal that leaves the board. The x-alignment is already
right (each terminal sits under its own pour's column); only the run down the
board and the side change are missing.

Run `docs/tools/conductor_sizing.py`, which models this gap; at 2 oz:

| Track width | R per phase | Dissipation, all 3 |
| --- | --- | --- |
| 3.0 mm (what the router will draw) | 1.52 mΩ | **11.4 W** |
| 5.0 mm | 0.91 mΩ | 6.8 W |
| 7.5 mm (full pour width) | 0.61 mΩ | 4.6 W |

At 3.0 mm this gap alone dissipates **more than all six FETs' conduction loss
combined** (10.5 W), and it is *in series with* the pours' own 6.7 W. That is
indefensible on a board whose reference design [47] already measures 103 °C at
this current.

Three ways to close it, in order of electrical cost:

1. **Move `J4A`/`J4B`/`J4C` to F.Cu and extend each phase pour down to its
   terminal.** Zero vias, zero added dissipation — the pour simply gets
   longer. Cost: the top side at y ≈ 48–58 currently holds `J2` (x 6.0) and
   `J3` (x 18.5), so those two solder-pad strips have to go somewhere else.
   This is a **placement** decision and therefore the repo owner's call.
2. **Keep the terminals on B.Cu, add a B.Cu phase pour per column, and stitch
   with a via field.** Needs **23 × 0.3 mm vias per phase** (2.2 A each) to
   present as much copper as the 2 oz pour — 69 vias total, in a region that
   also has to clear `U1`/`U2` and the resistor columns.
3. **Widen to full 7.5 mm pour on B.Cu without a matching via count.** Cheapest
   to draw and the easiest to get wrong: the via field, not the pour, becomes
   the narrowest point in the conductor.

Option 1 is the recommendation. Options 2 and 3 both pay for a layer change
the geometry does not actually require.

### Getting back into the flow after placing

```bash
kicad-cli pcb drc --severity-all <board>.kicad_pcb   # expect 0 errors first
python3 tools/autoroute.py --passes 60               # injects the net classes
kicad-cli pcb drc --severity-all <board>.kicad_pcb   # again, after routing
```

Then the fab outputs. Conductor sizing is still the blocking gap -- see below.

## Before you fabricate

**Conductor sizing is the blocking gap.** No conductor width on this board is
a computed value. IPC-2152 [46] is the governing standard; it is paywalled,
and only its Table of Contents has been read, so under `AGENTS.md` §1.3 no
width may be derived from it yet. `VM` and `GND` are poured planes and do not
depend on track width, but the three **phase** nets reach the motor connector
partly as routed track, and that is load-bearing at 50 A. See `TODO.md`
§12.4.k.

Also open before fab (all in `TODO.md` §12.4):

- **Real power connectors.** `J4` and `J5` are KiCad 6 mm² (~10 AWG)
  solder-wire pads — the largest in the stock library, chosen because the
  previous `J4` was a 2.54 mm pin header. No part has been selected and no
  current rating verified.
- **The isolation barrier width** follows from the transceiver variant, which
  is still open. The keepout is sized to clear the isolated pin rows, not to a
  creepage table.
- **Three engineering defaults need confirming**: the DRV8353S thermal pad
  tied to GND, the WE-SHC frame's locating holes plated, and the 10 kΩ
  pull-up values.
- **Placement is a starting point, not a solved layout.** It is DRC-clean and
  respects [21] §11.1's loop constraints, but thermal, EMI and
  manufacturability review of the power stage is a human task.
- **The MCU symbol maps 28 of the LQFP-64's 64 pins**, so 36 pads import with
  no net. Fine electrically (unused GPIO), but the symbol does not describe
  the whole package.

## tools/

Re-run these rather than hand-editing the generated `.kicad_sch`/`.kicad_pcb`.
Requires `kiutils` (schematic scripts) and KiCad's `pcbnew` Python module
(board scripts).

| Script | Purpose |
| --- | --- |
| `build_pcb.py` | Builds the PCB from the exported netlist: real footprints, every pad netted, outline, 4-layer stack, planes, phase pours, isolation keepout. |
| `autoroute.py` | FreeRouting round trip. Injects the power/sense net classes into the DSN — net classes live in the `.kicad_pro`, which `pcbnew.LoadBoard()` does not read, so without this every net routes at the 0.2 mm default. |
| `set_netclasses.py` | Writes the Power / Sense / Isolated classes into the project file. |
| `finish_annotate_and_footprints.py` | Annotation, footprint assignment, off-board flags. |
| `finish_erc_fixes.py` | The `R14` pull-up, the thermal-pad pin, the four power flags. |
| `add_power_connectors.py` | `J5` battery input; both power connectors off 2.54 mm headers. |
| `fix_generic_symbol_libs.py` | Moves the generic stand-ins into `Open_Secure_ESC_Generic.kicad_sym`. |
| `snap_to_grid.py` | Refuses to run without `--force`; documents why the snap shorts this sheet. |
| `check_shorts.py` | Finds collinear overlapping wire segments on different nets — a short KiCad's ERC reads as one net. |
| `gen_schematic.py` | **Carries a divergence warning.** No longer the sole author of the committed sheet; running it drops later work. |
| `gen_pcb.py` | Superseded by `build_pcb.py`. |

## Libraries (`sym-lib-table`)

| Nickname | Symbol | Pin-map status |
| --- | --- | --- |
| `MSPM0G3518_Q1_PM` | MCU, LQFP-64 | **VERIFIED** against [44] — real pin numbers, not placeholders |
| `OPTIGA_TRUST_M` | Secure element | VERIFIED, [45] p.17 Table 6 |
| `ADM3055E_ADM3057E` | CAN-FD transceiver | VERIFIED, full 20-pin |
| `ADM2582E_ADM2587E` | RS-485 transceiver | VERIFIED, full 20-pin |
| `DRV8353S` | Gate driver | VERIFIED, full 40-pin + thermal pad as pin 41 |
| `INA240` | Current-sense amp | VERIFIED |
| `IRFB4110PBF` | Power MOSFET | Standard TO-220AB pinout |
| `WSLP2512` | Shunt | Generic 2-terminal |
| `INR21700_P42A` | Cell (×6) | Generic 2-terminal; off-board |
| `WE_SHC_3670375` / `_3671375` | Shield frame / cover | Mechanical; cover is off-board |
| `Open_Secure_ESC_Generic` | R, C, C_Polarized, Conn_01x02/03/04, PWR_FLAG | This repo's own parts — **not** KiCad's `Device:`/`Connector_Generic:`/`power:` symbols; the pin geometry differs |
| `S32K144` | Superseded MCU | Retained so the old design history stays loadable; unused |

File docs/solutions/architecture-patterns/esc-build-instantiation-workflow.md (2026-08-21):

---
date: 2026-08-16
problem_type: architecture_pattern
category: architecture-patterns
module: builds
component: development_workflow
severity: high
applies_when:
  - "Starting a new builds/<voltage>/<amperage>/<variant>/ folder"
  - "Changing the power-stage topology (brushed vs brushless)"
  - "Adding a shaft-sensor interface to an existing build"
  - "Authoring a KiCad footprint from a manufacturer drawing"
  - "Taking any build from schematic to routed board"
tags:
  - esc
  - kicad
  - build-workflow
  - footprints
  - datasheet-verification
  - power-stage
  - erc-drc
related_components:
  - symbols
  - docs/decision-matrix.xlsx
  - REFERENCES.md
---

# Instantiating a new ESC build from amperage, voltage, shaft sensor and motor type

## Context

`builds/6s/50A/CAN_485_faraday/` was taken from a schematic with no reference
designators and a PCB whose every pad sat on net 0, through to an ERC-clean
schematic (0 errors), a netted 4-layer board with poured planes and an
isolation keepout, and a routed result (588 tracks, 88 vias, 114 → 23
unrouted). It was then respun for a 30 × 70 mm envelope.

Doing it once surfaced a set of traps that are not obvious from the KiCad
files and that will recur on every subsequent build. This document is the
repeatable procedure plus those traps.

**Two of the four inputs this workflow takes were missing axes.**
`docs/decision-matrix.xlsx` shipped with Voltage, Amperage, Protocol, Control
and EMI Hardening only. **Motor** and **Shaft Sensor** sheets were added
2026-08-16 (`docs/tools/add_motor_and_shaft_sensor_sheets.py`), and the whole
workbook now exports to `docs/decision-matrix.json` for scripting
(`docs/tools/decision_matrix_to_json.py`). Motor type is not a parameter
tweak — it changes the power-stage topology, the gate-driver part number, the
switch-position count and the shunt count.

**Status of the source build:** the 150 × 140 mm version reached routed +
DRC-clean-apart-from-cosmetics. The 30 × 70 mm respin is **in flight** — FET
and shield parts are selected, verified and footprinted; the schematic swap,
double-sided layout and re-route are not done. Nothing here should be read as
"the build shipped".

## Guidance

### Step 0 — Resolve the four axes into topology before touching KiCad

| Input | What it determines |
| --- | --- |
| **Motor type** | Bridge topology. Brushless → 3 half-bridges, 6 switch positions, a 3-phase gate driver, 3 phase shunts. Brushed → H-bridge, 4 switch positions, a different driver part, 1–2 shunts. **Different gate driver part number**, not a configuration bit. |
| **Amperage** | FET R_DS(on) and package, shunt value and power rating, conductor strategy, connector class, cooling requirement. |
| **Voltage (nS)** | FET V_DSS margin, bulk capacitor rating, isolation requirements. Pack max = nS × 4.2 V. |
| **Shaft sensor** | MCU pin budget, connector count, and extra BOM: Hall → 3 digital in + sensor supply; quadrature encoder → 2–3 inputs (+ index); resolver → excitation drive + a resolver-to-digital converter, a whole extra IC; sensorless → 3 phase-voltage dividers into ADC and no connector at all. |

Resolve these together. A sensorless brushed build and a resolver-fed
brushless build share almost no power-stage BOM.

### Step 1 — BOM, with verification discipline

Walk the decision matrix per axis, then apply `AGENTS.md` §1.3 to every line:
a part is not in the BOM until its **primary datasheet is held locally and
read**. Secondary corroboration is not verification. Record the verification
state in `symbols/specs/<PART>.json` `verification`, not in prose.

Screen **country of origin on every IC**, including parts you are copying
from a reference design (see Trap 4).

### Step 2 — Symbols from specs, never hand-edited

`symbols/specs/<PART>.json` is the source of truth; run
`symbols/tools/gen_kicad_symbol.py` to produce the `.kicad_sym`. The JSON
carries the citation and verification record, which is what makes the symbol
auditable.

### Step 3 — Footprints: find the published land before deriving one

See Trap 2 — this is where the most time was lost. Order of preference:

1. The manufacturer's published land pattern, wherever it lives.
2. A KiCad system footprint whose geometry you have **checked against** the
   manufacturer drawing.
3. An IPC-7351-style derivation, explicitly flagged per `AGENTS.md` §4.

Every generator's docstring must name the drawing each dimension came from
and state which numbers are derivations.

### Step 4 — Schematic to zero ERC errors

Annotate first (unannotated refs collapse the netlist). Then drive ERC errors
to zero. Warnings may remain if each is understood and documented; errors may
not. Read pin *types*, not just names — see Trap 6.

### Step 5 — PCB built from the exported netlist, not by hand

Generate the board from `kicad-cli sch export netlist` so the board cannot
drift from the sheet. Assign every pad its real net; report any pad with no
netlist node rather than leaving it on net 0.

Carry high-current nets as **planes and pours**, not tracks (Trap 5). Put a
copper keepout under any isolation barrier — a ground plane running beneath
an isolator defeats it.

### Step 6 — Route, then DRC

Inject net classes into the Specctra DSN (Trap 5). Re-pour zones after the
SES import.

## Why This Matters

Each trap below was found by a check, not by inspection, and each would have
produced a board that fails in a different way — a dead short, an
unbuildable land, a silently merged net, an export-controlled part, or a
conductor that melts.

### Trap 1 — Land-pattern datum errors are silent until DRC

TI's RTA0040B drawing dimensions `2X (5.8)` as the **centre-to-centre**
distance between opposite pad rows. Read as the outer copper extent, it puts
every pad 0.3 mm too far inboard and overlaps the corner pads — a dead short
between pin 1 (CPL) and pin 40 (VGLS). DRC caught it; reading the drawing had
not.

**Rule:** after reading a land pattern, verify it against an *independent*
dimension on the same drawing. For RTA0040B, calibrating on the 4.5 mm row
span (fixed by "36X 0.5") made three separate dimensions — pad centre axis
2.901, pad size 0.621 × 0.236, thermal pad 4.170 × 4.165 — all land on their
printed callouts simultaneously. Agreement across independent dimensions is
what distinguishes a measured value from a plausible one.

The same check validated the Würth shield: ring centreline from the land
pattern (10.35, 7.55) equals wall centreline from the body dimensions to the
last digit.

### Trap 2 — Where the land pattern lives is vendor-specific

| Vendor | Where the land pattern is |
| --- | --- |
| **TI** | In the part datasheet — "EXAMPLE BOARD LAYOUT" and "EXAMPLE STENCIL DESIGN" sheets. |
| **Toshiba** | **NOT in the part datasheet.** In the *MOSFET Product Catalog*, which tabulates package dimensions and land patterns side by side for the whole surface-mount family. |
| **Würth** | In the part datasheet, "Recommended Land Pattern". |
| **Infineon** | Not published for some packages (e.g. OPTIGA PG-USON-10) — derivation is unavoidable and must be flagged. |

Searching all 10 pages of the Toshiba TPHR8504PL datasheet for "land",
"mounting" and "recommend" returned nothing, which looked like "no published
land" and triggered an IPC derivation. The catalog had it. The derivation was
**46 % short on drain-land area and 86 % short on lead-pad area**.

**Rule:** a part datasheet with no land pattern means *check the vendor's
package/catalog document*, not *derive one*.

### Trap 3 — Bulk geometry transforms can short the sheet

`genlib.py` separates parallel routes by **0.01–0.02 mm lane offsets**, not
by whole grid steps. Snapping every coordinate to KiCad's 1.27 mm connection
grid — to clear 347 `endpoint_off_grid` warnings — collapsed those lanes onto
single grid lines and merged the nets.

Measured damage, 73 nets → 63: VM shorted to GND; all six PWM lines merged
into one net; CPH shorted to CPL across the charge-pump capacitor; NRST and
GD_SPI_MISO merged into 3V3.

**Rule:** export the netlist before and after any bulk geometry
transformation and require them identical. That diff is what caught this; the
transform itself looked correct and preserved every symbol-pin relationship.
`builds/6s/50A/CAN_485_faraday/kicad/tools/snap_to_grid.py` now
refuses to run without `--force`.

### Trap 4 — Screen country of origin in reference designs too

The Vimdrones S50 was mined as a technique reference for fitting 50 A into
40 × 17 mm. Its gate driver is a **Fortior FD62880 — Fortior Technology is
Shenzhen, PRC**. Copying the reference design's driver would have imported a
restricted-origin part while every other IC in this project is US/EU/Japan.

**Rule:** screen the manufacturer of every IC, and screen reference designs
before mining them for parts as opposed to technique.

### Trap 5 — The auto-router will route 50 A at 0.2 mm

Net classes live in the `.kicad_pro` **project** file. `pcbnew.LoadBoard()`
used standalone does not read it, so `ExportSpecctraDSN` puts every net in one
`kicad_default` class at the default width. The first routed board came back
with the pack net and all three motor phases on 0.2 mm track.

**Rule:** carry the current in copper pours and planes, and inject the net
classes into the DSN before routing. Verify afterwards by querying the actual
track widths per net — not by trusting the project settings.

### Trap 6 — Read pin *types*, not just pin names

DRV8353S `SDO` is type **OD**, and the datasheet states "This pin requires an
external pullup resistor." The schematic had none, so every SPI register read
from the gate driver would have failed silently. `nFAULT`, the other
open-drain pin, already had its pull-up — so the omission looked like a
complete design.

**Rule:** when transcribing a pin table, carry the *type* column into the
spec JSON, and treat OD/OC as a required-external-component flag.

### Trap 7 — Rated current is a thermal claim, not an electrical one

Vimdrones' instrumented test measured **103 °C at 50.18 A** with EDF airflow
at 29 °C ambient, and their own spec says "50 A (cooling required above
30 A)". A 50 A rating without a stated cooling condition is not a rating.

Related: a 1 mΩ shunt at 50 A dissipates I²R = **2.5 W into a 3.0 W part**
(83 % of rating, before derating, in a board already running hot). The
reference design used 0.5 mΩ, halving it.

## When to Apply

- Every new `builds/<voltage>/<amperage>/<variant>/` instantiation.
- Any time a footprint is authored from a manufacturer drawing.
- Before running a bulk coordinate transform on a generated schematic.
- Before auto-routing any board carrying more than a few amps.

## Examples

### Walking the axes from the JSON export

The workbook is the human-editable source; `docs/decision-matrix.json` is what
a build script reads. Rows are keyed by a slug of their first column, so
inserting a row never breaks a caller:

```python
db = json.load(open("docs/decision-matrix.json"))
v = db["axes"]["voltage"]["rows_by_key"]["6s"]  # 21.6 / 25.2 / 15.0 V
m = db["axes"]["motor"]["rows_by_key"]["brushless_bldc_pmsm"]
s = db["axes"]["shaft_sensor"]["rows_by_key"]["none_sensorless"]
```

**Check `Status` before consuming a row.** `unresolved_cells(db)` returns every
cell that is either explicitly TBD or sits on an `Open / unresolved` row —
currently the brushed-DC gate driver, all three sensored shaft-sensor options,
and SBus/DBus. A build script must refuse those rather than emit a BOM line,
per `AGENTS.md` §1.3.

### The verification gate at each phase

```text
Symbol      spec JSON `verification` names the datasheet section read
Footprint   generator docstring names the drawing; a second dimension
            on that drawing independently confirms the reading
Schematic   kicad-cli sch erc → 0 errors; every warning explained
Netlist     exported netlist identical across any geometry transform
PCB         every pad has a net; no pad left on net 0
Route       per-net track widths queried, not assumed
Fab         conductor sizing traced to a standard, or explicitly open
```

### What "engineering default" means in practice

Values that are judgement calls, not sourced, must say so at the point of
use — the 10 kΩ pull-up values, the connector selection, the gate-driver
thermal-pad net, the shield hole plating, and every conductor width in the
source build are all recorded this way per `AGENTS.md` §4. The discipline is
what makes the genuinely-verified numbers trustworthy.

## Related

- `AGENTS.md` §1.3 (no fabrication), §4 (design-decision rationale)
- `REFERENCES.md` — every citation tag used above
- `symbols/README.md` — footprint provenance table and the Toshiba catalog note
- `builds/6s/50A/CAN_485_faraday/kicad/README.md` — the source build's state
- `TODO.md` §12.4 — the open items this build carries into fab

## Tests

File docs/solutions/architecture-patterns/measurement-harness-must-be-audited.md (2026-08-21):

---
date: 2026-08-19
problem_type: architecture_pattern
category: architecture-patterns
module: builds
component: measurement_harness
severity: high
applies_when:
  - "A script decides whether a layout change is kept or reverted"
  - "A tool reports a metric nobody has cross-checked against the drawing"
  - "Automating placement, alignment, or DRC cleanup on a dense board"
  - "A result looks clean and no one can say which check would have caught it"
tags:
  - measurement
  - kicad
  - drc
  - placement
  - automation
  - verification
related_components:
  - builds/6s/50A/CAN_485_faraday/kicad/tools/score_placement.py
  - builds/6s/50A/CAN_485_faraday/kicad/tools/align_rows_columns.py
  - builds/6s/50A/CAN_485_faraday/kicad/tools/symmetrize.py
---

# The harness is the thing most likely to be wrong

Automated layout work on this project is gated by `score_placement.py`: apply a
change, refill, score, keep or revert on the number. That discipline is sound
and it caught real regressions. But over two sessions **five separate defects
were found in the measuring apparatus itself**, and every one of them had
already produced a confident, wrong conclusion that was acted on.

None was found by reading the harness. Every one was found by a result that
did not match the drawing.

## The five

| # | Defect | What it asserted |
| --- | --- | --- |
| 1 | Measured pad **centres**, not edges | 7.68 mm where the true gap was 2.51 mm; hid a 77.6 mm perimeter part entirely |
| 2 | `edge_path` ignored along-edge separation | U3 vs Q2 read 7.83 mm; true unfolded path 27.15 mm |
| 3 | Read only kicad-cli's `violations` array | "DRC electrical 0" while the change broke two GND connections |
| 4 | Layer compared by display-name substring | "0 of 59 footprints have courtyards" — all 59 had them |
| 5 | Group centre from the **mean** | Would have centred a column at 15.900 and called it 16.000 |

## What each one teaches

**1 and 2 — geometry, not proxies.** Clearance and creepage are edge-to-edge
across a surface. A centre-to-centre distance is a different quantity that
happens to have the same units. Creepage between opposite faces runs *around
the board edge* as an unfolded path, `sqrt(along_edge² + (insetA + T +
insetB)²)` — not the board thickness plus two insets, which silently assumes
both parts sit at the same point along that edge. They rarely do.

**3 — a tool's output has more than one channel.** `kicad-cli pcb drc` reports
broken connections in `unconnected_items`, a *separate array* from
`violations`. A harness reading one array is structurally blind to the other,
and blind in the worst way: it returns a confident zero. When wrapping a tool,
enumerate what it can report before deciding what to read.

**4 — compare by identity, not by name.** KiCad 9's `GetLayerName()` returns
the display name `"F.Courtyard"`; the canonical string is `F.CrtYd`. Testing
`"CrtYd" in GetLayerName(...)` cannot match, and reports absence rather than
error. Compare against `pcbnew.F_CrtYd` — the ID. The same applies to
`GetBoardEdgesBoundingBox()`, which measures the **outer extent of the
Edge.Cuts stroke** and overstates the board by one line width;
`GetBoardPolygonOutlines()` is the outline. That 0.05 mm has now caused two
separate errors here.

**5 — the summary statistic encodes an assumption.** The mean of a column
whose members include one deliberately offset part is not that column. The
median is. Ask what the number is *for* before picking how to reduce a group
to one value.

## The pattern

Each defect made the harness **more permissive or more alarming than reality**,
and in both directions the failure was silent. A wrong number does not raise;
it gets believed, written into a commit message, and acted on. In this project
one such number was committed under a message asserting DRC results the
committed file did not have.

**So: a harness earns trust by being checked against the artefact, not by
being read.** Before trusting a metric to gate real changes, hand-verify one
case against the drawing — pick the result you would be most embarrassed to
have wrong, and measure it independently.

## Two corollaries for automated placement

**The majority is not automatically the target.** `align_rows_columns.py`
first snapped outliers onto whatever position most of a group shared. On the
high-side FETs that moved Q1 *away* from its gate driver and lengthened the
worst gate loop, so the guard reverted it and the row stayed crooked. The
right move was the opposite — bring the majority to the minority — which
aligned all six FETs *and* shortened the commutation loop. Score every
candidate, not the popular one.

**Cosmetic goals can conflict, and the conflict is arithmetic.** Centring a
mirror pair splits its separation in half, so a pair 8.500 mm apart lands at
±4.250 — symmetric and off a 0.5 mm grid. Symmetry and grid alignment coexist
only when separations are whole millimetres. When resolving it, round in the
direction that is *electrically* safer: this board's pack terminals went
outward, 8.500 → 9.000, gaining clearance rather than losing it.

## Related

- [[isolation-geometry-sets-board-aspect]] — the creepage geometry that
  defects 1 and 2 were mismeasuring.

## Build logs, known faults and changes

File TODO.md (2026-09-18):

# TODO.md — Work Breakdown Structure

Governed by `AGENTS.md`. Status: `[ ]` open, `[~]` in progress, `[x]` done,
`[!]` blocked. `Cn` = REFERENCES.md tag needed/used. Keep entries terse;
detail belongs in design docs, not here.

## 1. Governance & Docs

- [x] 1.1 AGENTS.md — contributor/agent rules
- [x] 1.2 REFERENCES.md — IEEE bibliography scaffold
- [x] 1.3 TODO.md — this WBS
- [x] 1.4 Verify [1] MSPM0G3507 datasheet doc ID/rev/page (local copy
      verified 2026-08-02; live ti.com fetch blocked: 403). **[1] superseded
      2026-08-03 — project MCU changed, see 13.**
- [x] 1.5 Verify [2] SLB9672 datasheet page refs for compliance claims — DROPPED
      (external TPM removed; see 4.1).
- [x] 1.13 **ti.com/lit datasheet access restored** (2026-09-17): the HTTP 403
      block recorded against [1] (1.4) no longer applies — [62], [63], [65]
      and [66] were fetched live from `https://www.ti.com/lit/ds/symlink/…`
      and verified locally. Entries that still say "live fetch blocked" are
      historical notes, not current state.
- [~] 1.11 Verify [31] NXP S32K1xx Data Sheet claims used historically (local
      copy VERIFIED); S32K144 removed as project MCU (see 13). Keep artifacts
      for audit/history; do not reuse the S32K144 symbol as an active part.
- [x] 1.12 `docs/security-mcu-comparison.md` — updated to reflect MCU swap and
      Trust M justification; ensure any claim referencing MCU crypto or SHE
      is traced to an authoritative source (Cn).
      **Closed 2026-08-22** (see `TODO.md` 13.1.h): a superseded-status
      banner now points the document at the actual decision
      (MSPM0G3518-Q1, [44]) and at `docs/secure-element-architecture.md`
      for current architecture; the S32K144-vs-alternatives body is kept as
      historical record, its claims already cited to [31]/[2]/[33]/[35]–[43].

## 2. Requirements

- [ ] 2.1 Functional requirements spec (per voltage/amperage/protocol/control/EMI variant)
- [ ] 2.2 Safety requirements (motor runaway, overcurrent, thermal, CSEc/SE-based message-authentication trust boundary)
- [ ] 2.3 Regulatory/EMC targets per market (cite standard, Cn)
- [ ] 2.4 Requirements traceability matrix → REFERENCES.md tags
- [ ] 2.5 Motor speed-sensor requirement (ALL variants): define required accuracy, latency, interfaces and failure modes; enumerate supported sensor types (Hall/low-voltage digital, optical encoder/quadrature, analog tachometer → ADC). Trace to authoritative references where applicable (Cn). See `docs/design-speed-sensor-integration.md`.
- [x] 2.6 Environmental & ingress protection requirements: Form Factor × Ingress resolved as a joint axis (two variants: splash/spray air-cooled IPX4–6, sealed/immersion IPX7–8), with the cited standards, layered-boundary design, and thermal/waterproofing interaction fully authored in `docs/design-waterproofing-and-thermal-management.md`. Remaining sub-items tracked below (Cn where marked).
  - [ ] 2.6.a Select an IPC-CC-830C [57]-qualified conformal coating for the faceted board with its Flexibility (§3.5.5) and Thermal Shock (§3.7.2) data obtained from a vendor datasheet, not assumed from coating type alone (Cn).
  - [ ] 2.6.b Select a wire-egress connector/gland series with a manufacturer-stated IP rating at the mated condition; hold its datasheet locally (Cn).
  - [ ] 2.6.c Size the pressure-equalization vent (ePTFE membrane, e.g. [58]) against bay free volume and design altitude/thermal excursion — no sizing method is catalogued yet (Cn).
  - [ ] 2.6.d Verify whether IEC 60529 Amendments 1/2 changed the IPX4/6/7/8 clause numbers or definitions relative to the 2001 text held locally as [56] (Cn).
  - [ ] 2.6.e Decide, for the sealed/immersion variant, whether service access (compression gasket) or potting is required — a requirements decision, currently open.

## 3. Hardware — MCU Subsystem

- [~] 3.1 S32K144 schematic (historical) — kept for record; S32K144 removed as active MCU.
- [~] 3.2 Programming/debug interface — update mapping to new MCU (see 13).
- [~] 3.3 Peripheral pin mapping vs. protocol variant matrix — update and verify for MSPM0G3518-Q1 (Cn).
- [~] 3.4 Motor speed-sensor pin/interface mapping: allocate pins + ADC channels/OPAMP/COMP/interrupts/Quadrature timers for Hall/encoder/analog tach across the active MCU symbol/spec; add to `symbols/specs/*` and per-build variants. Mark pin numbers UNVERIFIED until primary-source pinmap read (Cn).

## 4. Hardware — Trust/Security Subsystem

- [x] 4.1 External SLB9672 TPM (historical) — removed 2026-08-03. OPTIGA™ Trust M (`U2`) integrated for asymmetric identity where required — see `docs/secure-element-architecture.md` and `docs/design-se-integration.md`.
- [ ] 4.2 Secure boot / attestation chain design doc (CSEc + Trust M): finish and VERIFY against primary sources (Cn).
- [ ] 4.3 Key provisioning process (Trust M provisioning profile, platform binding secret, SE Shielded Connection) — MUST be specified & verified (Cn).
- [ ] 4.4 CSEc firmware integration: message authentication (CMAC generate/verify per SHE); reconcile clock/CSEc execution budget vs hot-path control timing (Cn).

## 5. Hardware — Power Stage

- [~] 5.1 Gate driver + FET selection per amperage tier (10/20/30/40/50/80/120 A) — maintain candidate list; verify datasheets for final BOM lines (Cn).
- [~] 5.2 Voltage tier variants (2S/4S/6S/8S/12S) — component derating table; verify cell choices (Cn).
- [~] 5.3 Current sensing (shunt/hall) selection + citation — verify across tiers; INA240/WSLP candidates remain.
- [~] 5.4 **First instance built 2026-09-17** — `builds/6s/10A/BRUSHED_CAN_485_isolation/` (Tier-1 DRV8874-Q1 [63] integrated bridge, IPROPI current sense, brake driver; see §18). Remaining: Tier-2/3 discrete-FET brushed stages. Original text: Brushed-ESC power-stage variant: add H-bridge / half-bridge design task, BOM candidate(s), protections (reverse current, flyback diodes, current sensing placement), and interaction with control firmware. See `docs/design-brushed-esc-variant.md`. Mark part-selection claims UNVERIFIED until datasheets cited (Cn).

## 6. Hardware — Protocol Interfaces

- [ ] 6.1 PWM input stage
- [ ] 6.2 SBus input stage (flag UNVERIFIED spec, C-pending)
- [ ] 6.3 DBus input stage (flag UNVERIFIED spec, C-pending)
- [ ] 6.4 UART/TTL transceiver
- [ ] 6.5 SPI interface
- [~] 6.6 RS-232 transceiver per [3]; candidate part ADM3232E [Cn]
- [ ] 6.7 RS-485 transceiver per [4]; candidate part ADM2582E/ADM2587E [Cn]
- [ ] 6.8 CAN 2.0 controller/transceiver per [5]; candidate part ADM3055E/ADM3057E [Cn]
- [ ] 6.9 CAN-FD controller/transceiver per [6]; candidate part ADM3055E/ADM3057E [Cn]
- [ ] 6.10 MIL-STD-1553B interface per [7]; candidate module Alta MEZ-E1553 [Cn]
- [ ] 6.11 Motor speed-sensor interfaces (ALL variants required):
      - 6.11.a Hall-effect: digital input(s) with interrupt and optional differential input path.
      - 6.11.b Quadrature encoder: A/B ±index input with pull resistors and optional hardware quadrature decoder (or ISR fallback).
      - 6.11.c Analog tachometer: analog front-end → ADC channel with anti-alias filtering, input protection and op-amp/comp front-end where needed.
      Add BOM candidates, level shifting, input protection and EMI filtering guidance; cite datasheets/standards where applicable (Cn). See `docs/design-speed-sensor-integration.md`.

## 7. Hardware — EMI Hardening

- [~] 7.1 Define tier requirements: None / Isolation / Grounding / Faraday; source clauses (Cn).
- [ ] 7.2 Layout guidelines per tier
- [ ] 7.3 Pre-compliance test plan
- [ ] 7.4 EMI considerations for speed-sensor inputs: ground referencing, filtered inputs for analog tach, twisted-pair differential routing for encoder/Hall lines, comparator hysteresis, input common-mode and ESD protection. Add to layout checklist and per-build README.

## 8. Firmware

- [ ] 8.1 Control loop: Open-loop
- [~] 8.2 Control loop: Closed-loop differential — sensorless FOC (where applicable) and sensors fallback.
- [~] 8.3 Control loop: Closed-loop PID
- [ ] 8.4 Protocol drivers (per §6)
- [ ] 8.5 Secure-boot / trust-chain firmware integration (CSEc + Trust M)
- [ ] 8.6 Fault handling (overcurrent/thermal/comm-loss)
- [ ] 8.7 Brushed-ESC firmware variant: H-bridge control, commutation strategy, regen handling, and safety limits. See `docs/design-brushed-esc-variant.md`. **2026-09-17:** the first brushed build's firmware requirements (cascade, brake sequencing, nFAULT-as-brake-engage, rail-droop rule, jam detection, trip input, per-side sense, brake-release authorization with asymmetric MAC fail policy) are recorded in `builds/6s/10A/BRUSHED_CAN_485_isolation/README.md` "Firmware requirements" — implement against that list.
- [ ] 8.8 Motor-speed sensor drivers and abstractions (common API): Hall (edge interrupts + debounce), quadrature decoder (hardware timer or ISR fallback), analog tachometer (ADC sampling + filtering). Include failure modes and fallback behavior per safety reqs (2.2).
- [ ] 8.9 Sensor fusion + control use-cases: map sensor input selection to control loop modes (sensorless fallback → sensor-based closed-loop), calibrations, and per-build configuration stored in NVM.

## 9. Verification & Test

- [ ] 9.1 Unit test plan (firmware)
- [ ] 9.2 HIL bench test plan
- [ ] 9.3 EMC pre-compliance test
- [ ] 9.4 Protocol conformance test per interface
- [ ] 9.5 Motor-speed sensor functional tests (Hall pulse-train test, encoder quadrature correctness, analog ADC calibration & accuracy)
- [ ] 9.6 Brushed power-stage test procedures (H-bridge switching, dead-time verification, reverse-current handling)

## 10. Release

- [ ] 10.1 Design review gate (AGENTS.md §5 checklist)
- [ ] 10.2 BOM finalization per variant (include sensor lines for every variant)
- [ ] 10.3 Manufacturing/fab release
- [ ] 10.4 v1.0 documentation freeze

## 11. Shared KiCad Symbol Library (symbols/)

- [x] 11.1 Generator + JSON-spec workflow (`symbols/tools/gen_kicad_symbol.py`, `symbols/specs/*.json`) retained.
- [x] 11.2 Historical S32K144 symbols retained for audit, not active.
- [~] 11.7 Active MCU symbol: author `symbols/specs/MSPM0G3518_Q1_PM.json` + `.kicad_sym` (work in progress). Pin numbers remain `UNVERIFIED PLACEHOLDER` until the primary pinmap is extracted/verified (Cn).
- [x] 11.4/11.5 previously VERIFIED symbols retained.
- [ ] 11.8 Add sensor symbols & footprint candidates: Hall sensor (digital), quadrature encoder connector, analog-tach front-end parts (OPAMP/COMP), level-shifters and input protection devices. Add generator JSON entries for each and ensure tools can emit them for each build variant.

## 12. Per-Build Instances (builds/`<voltage>`/`<amperage>`/`<variant>`/)

- [~] 12.1 `builds/6s/50A/CAN_485_faraday/` — 6S, 50A, CAN-FD + RS-485
      (concurrent), Faraday EMI tier (sized against a 500 W/m² broadband RF
      requirement, derived ~434 V/m). BOM drafted from
      `docs/decision-matrix.xlsx` (README.md in that folder); `kicad/`
      contains a project skeleton wired to `symbols/` but no placed
      components; `gerbers/` empty pending a PCB layout. Blocked on the
      same open items as 1.10/5.1-5.3/6.7-6.9/7.1: most BOM lines are still
      `Candidate (unverified)`, and the CAN-FD/RS-485 transceiver variant
      choice (isolation voltage vs. data rate) and DRV8353S-vs-INA240
      current-sense sourcing are open design questions, not resolved in
      that build's README.
      **2026-08-03: MCU/TPM swap applied to this build** — U1 is now
      S32K144 (was MSPM0G3507), the SLB9672 TPM (U2) was removed, schematic
      and PCB regenerated via `kicad/tools/gen_schematic.py`/`gen_pcb.py`
      (connectivity check clean, `check_shorts.py` clean, kiutils
      round-trip validated). See 1.11/3.1/4.1 for what's still open.

- [~] 12.3 Secure element (`U2`, OPTIGA™ Trust M V3, [45]) — added to
      `builds/6s/50A/CAN_485_faraday` 2026-08-10. Symbol, footprint, 3D model,
      schematic placement and LPI2C wiring are **done and verified** (pin map
      from [45] p.17 Table 6; reference circuit from [45] p.12 §3 Fig. 2; ERC
      shows no new errors). Design rationale and the full assessment are in
      `docs/secure-element-architecture.md`. The items below are **OPEN and
      must be closed before this build flies** — they are firmware and policy
      decisions, not layout work.
  - [ ] 12.3.a **(High, safety-critical)** Define the behaviour on CSEc MAC
        verification failure. If a failed MAC hard-stops a motor in flight,
        a single corrupted frame — or a transient bus fault — becomes a
        shutdown primitive, i.e. the security control becomes the attack.
        Decide fail-operational vs fail-safe and over what window of
        consecutive failures. See `docs/secure-element-architecture.md` O-04.
    - [x] 12.3.a.i **Resolved for the 6S/10A brushed build only (2026-09-17):**
          fail-safe = brake engaged, motor coasting; fail-operational applies
          only to a MAC failure on a position frame (hold the last valid
          command, never engage mid-manoeuvre); a MAC failure on a
          brake-release command leaves the brake engaged. Recorded in
          `builds/6s/10A/BRUSHED_CAN_485_isolation/README.md` (fail-state
          table). The fleet-wide question above stays open.
  - [ ] 12.3.b **(High)** Specify an anti-replay freshness scheme. AES-128
        CMAC authenticates content, not recency; without a freshness value a
        recorded throttle command replays as valid. The Trust M's 4 monotonic
        counters ([45] p.10 Fig. 1) are boot-scale and cannot serve per-frame.
        See C-03.
  - [ ] 12.3.c **(High)** Enable the Trust M I²C **Shielded Connection** and
        provision the platform binding secret ([45] p.1 Features, p.10 Fig. 1).
        Without it the agreed session key crosses an exposed 2-wire bus in
        clear and the whole asymmetric layer buys nothing against an attacker
        with board access. See C-06.
  - [ ] 12.3.d **(Medium)** Decide `MAC_LENGTH` for CAN-FD frames and the
        verification-failure rate limit. CAN-FD carries at most 64 byte
        ([31] RM Rev. 14 §55.2.2, p. 1802); a full 128-bit CMAC is 16 byte.
        Truncation to 32 bit gives 2⁻³² per attempt, which is insufficient
        without a lockout. Interacts directly with 12.3.a. See C-04.
  - [ ] 12.3.e **(Medium)** Reconcile the control-loop clock budget with the
        CSEc/HSRUN exclusion: [31] §1.1 states the device must drop from
        HSRUN (112 MHz) to RUN (80 MHz) to execute CSEc. Any budget assuming
        112 MHz *and* per-frame CMAC is wrong. See C-05.
  - [ ] 12.3.f **(Medium)** Design fleet key lifecycle and revocation. With 4
        certificate slots and 3 trust anchors there is no room for a
        conventional CRL, and there is no defined process for retiring a
        compromised controller. See O-05.
  - [ ] 12.3.g **(Low)** Pin the ECC curve in the provisioning profile
        (P-256 minimum, P-384 preferred). The device also supports RSA-1024
        ([45] pp. 8–9 Table 4), which must not be selected. See C-07.
  - [ ] 12.3.h Port the secure-element placement into
        `kicad/tools/gen_schematic.py`. It was deliberately **not** written
        blind: `kiutils` is unavailable on the machine where this work was
        done, so the code could not have been executed even once, and
        unverified generator code that silently overwrites a verified
        schematic is precisely what `AGENTS.md` §1.3 guards against. The
        schematic was extended by `kicad/tools/inject_optiga_secure_element.py`
        instead, and `gen_schematic.py` now carries a divergence warning. Do
        this on a machine with `kiutils`, then diff against the committed
        sheet before trusting the result.
  - [ ] 12.3.i Annotate the sheet. Every reference on
        `open_secure_esc_6s_50a_can485_faraday.kicad_sch` is still `R?`/`C?`/
        `U?`, which is why a netlist export collapses passives. Pre-existing,
        but it blocks BOM/CPL generation and PCB placement of `U2`.
  - [ ] 12.3.j Place `U2` and its three passives on the PCB
        (`gen_pcb.py` / manual). Schematic-only at present.

- [~] 12.4 **Layout completion pass for `builds/6s/50A/CAN_485_faraday`**
      (2026-08-15). The build went from "schematic populated, PCB net-less and
      unrouted" to an annotated schematic with **0 ERC errors** and a
      4-layer PCB carrying every part, real nets, poured planes and routed
      copper. Generators live in that build's `kicad/tools/`. What was closed:
  - [x] 12.4.a Schematic annotated — all 57 symbols; closes 12.3.i. The 8
        `PWR_FLAG` symbols were also virtualised (`#FLGnn`, out of BOM, off
        board); they had been ordinary in-BOM parts.
        (`tools/finish_annotate_and_footprints.py`)
  - [x] 12.4.b **DRV8353S footprint authored** from TI's own RTA0040B
        EXAMPLE BOARD LAYOUT / EXAMPLE STENCIL DESIGN sheets [21] — closes the
        "No footprint for U5" gap. Land, paste apertures and the 12x 0.2 mm
        thermal vias are manufacturer values, not an IPC derivation.
        (`symbols/tools/gen_drv8353s_rta0040b_footprint.py`)
  - [x] 12.4.c **WE-SHC 3670375 frame footprint authored** from Wurth's own
        Recommended Land Pattern [30]. The 3671375 COVER correctly gets no
        footprint — it clips on and is not soldered, so it is now
        schematic/BOM-only like BT1-BT6.
        (`symbols/tools/gen_we_shc_3670375_footprint.py`)
  - [x] 12.4.d **Missing SDO pull-up added (R14, 10k).** [21]'s pin table
        gives DRV8353S SDO (pin 27) as type **OD** and states "This pin
        requires an external pullup resistor." There was none, so every SPI
        register read from the gate driver would have failed. nFAULT already
        had its pull-up (R11); SDO did not.
  - [x] 12.4.e **Gate-driver thermal pad given electrical existence.** Pin 41
        added to the DRV8353S symbol and tied to GND, so the exposed pad is
        not imported as an isolated copper island under the power stage. The
        GND assignment is an engineering default — see 12.4.n.
  - [x] 12.4.f **Four isolated-side power flags reconnected.** #FLG04-07 and
        their L-routes never touched their target pins (legs landed on the
        right Y at x = 381.5 while the pins are at x = 380.01), leaving 4
        `power_pin_not_driven` errors on the transceivers' isolated supplies.
        Replaced with short stubs and rail labels.
  - [x] 12.4.g **32 `lib_symbol_mismatch` warnings cleared** by moving the
        generic R/C/connector/flag stand-ins into a repo-owned library,
        `symbols/Open_Secure_ESC_Generic.kicad_sym`. They had been stored
        under KiCad's own `Device:`/`Connector_Generic:`/`power:` names
        despite different pin geometry. `kicad/README.md`'s claim that these
        are "KiCad's own standard" parts was wrong and is now corrected.
  - [x] 12.4.h **Battery input added (J5).** VM had no connector at all — the
        pack is off-board, so the board could not be energised. The previous
        PCB had a J5 footprint with no schematic counterpart, i.e. two netless
        pads. J5 is now a real schematic part on VM/GND.
  - [x] 12.4.i **PCB rebuilt from the exported netlist** — 44 footprints, 73
        nets, every pad netted from the schematic rather than left on net 0.
        4-layer stack: In1.Cu solid GND, In2.Cu VM over the power stage and
        GND elsewhere, GND pours on both outer layers.
        (`tools/build_pcb.py`)
  - [x] 12.4.j **Isolation barrier made real** — a copper keepout removes
        every plane and pour from the isolated band, and both transceivers are
        rotated so their isolated pin rows face the board edge. Without it the
        GND plane ran straight under the isolation barrier.
  - [ ] 12.4.k **(High, blocks fab) Size the power conductors against
        **Cross-reference added 2026-08-20:** 12.5.ba now carries the
        conductor/via arithmetic and the corroborated secondary sources
        ([S-A]-[S-F] in `REFERENCES.md`); 12.5.bb adds the altitude question.
        This item remains the one that closes when a primary standard is in
        hand. **IPC-2152 is the document to buy.**
        IPC-2152 [46].** No conductor width in this build is a computed value.
        VM and GND are poured planes so they do not depend on track width, but
        the three PHASE nets reach the motor connector partly as routed
        track, and that IS load-bearing at 50 A. [46] is paywalled: only its
        Table of Contents has been read, so per `AGENTS.md` §1.3 nothing may
        be derived from it yet. Buy the standard, then size the phase copper,
        the plane cross-sections, the vias and the connector pads, and choose
        the copper weight to match.
  - [ ] 12.4.l **(High, blocks fab) Select real power connectors.** J4
        **Partly stale as written, verified 2026-08-20:** J4A/B/C are now
        `SolderWirePad_1x01_SMD_5x10mm` and J5A/B are
        `SolderWire-6sqmm_1x01_D3.5mm_OD7mm` converted to SMD, so the
        footprints have moved on. **The substance stands: no connector has
        been selected and no current rating verified.**
        (phases) and J5 (pack) are currently KiCad 6 mm^2 (~10 AWG) solder-wire
        pads — the largest in the stock library, chosen because the previous
        J4 was a 2.54 mm pin header, which is not a 50 A part. No connector
        has actually been selected and no current rating verified. Depends on
        12.4.k.
  - [ ] 12.4.m **(Medium) Set the isolation barrier width from the chosen
        **DUPLICATE of 12.5.ae (2026-08-20) — track it there.**
        transceiver variant.** The keepout band is sized to clear the isolated
        pin rows, not to any creepage/clearance table. The real figure follows
        from the still-open ADM3055E-vs-ADM3057E (5000 vs 3750 V rms) and
        ADM2582E-vs-ADM2587E choices in this build's README.
  - [ ] 12.4.n **(Medium) Confirm the DRV8353S exposed pad may be tied to
        **Verified 2026-08-20: the board does tie it to GND** (`U5` pad 41 net
        = GND). The open question is the datasheet confirmation, not the
        implementation.
        GND.** [21] requires the pad to be soldered (RTA0040B note 3) and
        requires a ground-plane connection at the GND pin (§11.1), but does
        not state that the pad is internally common with GND. Currently an
        engineering default per `AGENTS.md` §4.
  - [x] 12.4.o **SUPERSEDED 2026-08-20 — the part it asks about is not on
        the board.** This concerned the WE-SHC **3670375** locating holes. The
        shield was swapped to **3670209** in 12.5.c; verified on the board
        2026-08-20, `SH1` is `Wurth_WE-SHC_3670209_Frame_15.3x20.9mm`, 8 pads.
        If the 3670209's locating features need the same plating decision,
        raise it against [51]/[52] as a new item, not this one.
  - [ ] 12.4.p **(Medium) Model the MCU's remaining 36 package pins.**
        **Verified 2026-08-20: still exactly true** — `symbols/specs/
        MSPM0G3518_Q1_PM.json` maps 28 pins and U1 has 28 of 64 pads on a real
        net.
        `symbols/specs/MSPM0G3518_Q1_PM.json` maps 28 of the LQFP-64's 64
        pins, so 36 pads import with no net. Fine electrically (unused GPIO),
        but the symbol does not describe the package.
  - [x] 12.4.q **SUPERSEDED 2026-08-20 — `build_pcb.py`'s placement table
        has not been the board's placement since 2026-08-16.** The repo owner
        hand-placed it (12.5.f); it has since been widened (12.5.ac), aligned
        (12.5.ap), symmetrised (12.5.aq), had U7/U8 re-assigned (12.5.ar),
        U1/U5/SH1 centred (12.5.as), and seven passives moved out of the
        shield ring (12.5.ay). The remaining placement questions are tracked
        specifically in 12.5.z, 12.5.ax and 12.5.ay rather than as one
        open-ended item. **The thermal/EMI human review this item asks for is
        real and still outstanding** — carried to 12.4.k and 12.5.bb.
  - [ ] 12.4.r **(Low) 347 `endpoint_off_grid` ERC warnings.** `genlib.py`
        **Count corrected 2026-08-20: 463, not 347** — it grew with the
        isolated-supply and J1 schematic work. 7 `global_label_dangling` also
        remain; 470 ERC violations total, 0 errors. The analysis below is
        unchanged and still correct.
        lays the sheet out on a 10 mm grid, which is not a multiple of KiCad's
        1.27 mm connection grid. **Do not "fix" this with a coordinate
        snap** — it was tried and reverted: the generator separates parallel
        routes by 0.01-0.02 mm lane offsets, and snapping merges them
        (VM shorted to GND, all six PWM lines merged, CPH shorted to CPL;
        73 nets collapsed to 63). See `tools/snap_to_grid.py`, which now
        refuses to write without `--force`. A real fix means re-laying out
        the drawing with >= 1.27 mm lane spacing.
  - [x] 12.4.s **SUPERSEDED 2026-08-20 — the counts are from a board three
        respins ago.** Measured on the current board: **11 `silk_over_copper`,
        7 `silk_overlap`, 2 `isolated_copper`, 0 `starved_thermal`** — 20 DRC
        violations, all cosmetic; zero shorts, clearance or isolation.
        Silkscreen carries forward as 12.5.u, the `isolated_copper` as
        12.5.at.
- [~] 12.5 **Compact respin of `builds/6s/50A/CAN_485_faraday`, landed at
      25.4 x 60.1 mm** (2026-08-16). Triggered by the repo owner: the
      150 x 140 mm board from 12.4 was "way too big for a single channel ESC
      ... it won't fit where it needs to". Drawn for a 30 x 60 envelope, then
      hand-placed by the repo owner and narrowed to 1 inch wide without
      shrinking any phase pour. Schematic complete and ERC-clean; placement
      converged. **Next session starts at 12.5.t.**
  - [x] 12.5.a **FET swapped to Toshiba TPHR8504PL** [49], package 2-5W1A
        "SOP Advance(N)", chosen by the repo owner over TI CSD19532Q5B [48].
        Symbol, spec and footprint authored. TO-220 -> SMD is what makes
        double-sided assembly possible at all.
  - [x] 12.5.b **Land pattern taken from Toshiba's catalog** [50] p.46, not
        derived. An IPC-7351 derivation made first (before [50] was located)
        was 46% short on drain-land area and 86% short on lead-pad area.
        Toshiba does not publish land patterns in part datasheets.
  - [x] 12.5.c **Shield swapped to WE-SHC 3670209/3671209** [51]/[52],
        saving 812 mm^2 -- the single biggest area win available.
  - [x] 12.5.d Shunts 1 mOhm -> **0.5 mOhm**; C1 radial -> 1210 SMD;
        J4/J5 split into per-terminal pads; J1-J4 moved to SMD solder pads.
  - [x] 12.5.e **Schematic swap complete, 0 ERC errors.** All six gate nets
        preserved by placing the new symbol so its gate pin lands on the old
        gate pin's exact coordinate; drains and sources rewired and the
        netlist verified pin-by-pin (high-side drains on VM, low-side drains
        on the phases, low-side sources on the shunts).
  - [x] 12.5.f **Hand-place the PCB -- DONE by the repo owner** (2026-08-16),
        then narrowed to 25.4 x 60.1 mm. DRC: **0 courtyard overlaps, 0
        clearance, 0 hole-clearance, 0 same-layer pad conflicts.** Tightest
        copper-to-edge 0.83 mm (U3). Constraints that must survive future
        edits are tabulated in `kicad/README.md` "Placement guide".
        Re-running `tools/build_pcb.py` discards this placement -- its
        PLACEMENT table still describes the old 30 x 60 layout.
  - [x] 12.5.g **(High, electrical) U5's thermal via field vs the FETs --
        RESOLVED by the hand placement** (verified 2026-08-16: no U5 thermal
        via intersects any pad of any other footprint). Kept below as the
        standing re-check after any move of U5 or a Q.**
        U5 sits on the bottom directly beneath the top-side MOSFETs and its
        footprint carries 12 thermal vias on GND. A via under a FET drain pad
        shorts **GND to VM or to a phase**. [21] RTA0040B note 5 makes the
        vias optional, so deleting them is a legitimate fix. Check after any
        move of U5 or any Q.
  - [x] 12.5.p **Conductor sizing answered as an interim derivation**
        (2026-08-16). `docs/tools/conductor_sizing.py` derives phase-pour
        resistance and dissipation from copper's resistivity: **2 oz outer is
        the floor**, because at 1 oz the three phase pours dissipate 13.3 W
        against the FETs' 10.5 W -- the copper would be the dominant heat
        source. A phase changing layers needs ~23 x 0.3 mm vias to match the
        pour. This is an AGENTS.md Sec.4 engineering derivation giving WATTS,
        not degrees; **IPC-2152 [46] stays open** (12.4.k) because turning
        watts into temperature rise is exactly what it provides and this does
        not.
  - [ ] 12.5.q **(High) Set IDRIVE from a bench measurement, not a table.**
        Overshoot is 25.2 + L_loop x dI/dt. At 5 nH every IDRIVE setting is
        survivable; at 20 nH almost none are. Minimise the commutation loop
        first, then raise IDRIVE as far as measured V_DS allows. Table in
        `kicad/README.md`. Closes the open half of 12.5.n.
  - [ ] 12.5.r **(Low) Two PCB reference sets were consulted 2026-08-16 and
        both need treating with care.** One labelled the **IPC-2221**
        Appendix A equation (k=0.048/0.024, b=0.44, c=0.725) as "the IPC-2152
        formula" -- different standards, and 2152 exists because 2221's curves
        were found inaccurate -- and its own quick-reference table disagreed
        with that formula by ~2x at 10 A. Neither was used as a source. Noted
        so nobody adopts those numbers later believing they are IPC-2152.
  - [ ] 12.5.h Route (`tools/autoroute.py`), then DRC to zero errors.
        **2026-08-20: superseded in practice by 12.5.av (the routing pass) and
        blocked by 12.5.bf.** Kept as the parent goal; do not work it directly.
  - [ ] 12.5.i Fab outputs, then documentation.
  - [x] 12.5.j **Where the next session picks up** -- superseded; placement
        is done (12.5.f) and 12.5.g is resolved. See 12.5.t.
  - [ ] 12.5.k **(Medium) Strain relief for J2/J3.** They are now bare SMD
        solder pads with no mechanical retention, and they leave the board in
        service. J1 (debug) is fine as-is. Needs a tie-down, potting, or a
        real connector selected.
  - [ ] 12.5.l **(Medium) On-board bulk capacitance.** C1 went from a 10 mm
        radial to a 1210, which holds far less. [47] carries 470 uF 63 V
        EXTERNAL to the board. Decide whether external bulk is required.
  - [ ] 12.5.m **(Medium) Confirm the sense chain still resolves.** Halving
        the shunt halves the sense voltage; check the DRV8353S CSA gain and
        the INA240 range against the overcurrent trip threshold.
  - [ ] 12.5.n **(High, carried from the FET choice) Bound the drain
        overshoot.** [49] is a 40 V part on a 25.2 V pack -- 1.59x, down from
        3.97x. Set the DRV8353S IDRIVE slew rate via SPI and bench-measure
        V_DS at the switching node before fab.
  - [ ] 12.5.o (Low) `tools/respin_30x70_schematic.py` is named for the
        70 mm target that became 60 mm. Rename or note it.
  - [~] 12.5.s **(electrical) VM HAD NO TOP-SIDE COPPER -- top-side half
        DONE 2026-08-16, via stitching still open.** The VM
        plane is on **In2.Cu only**, but every part carrying pack current is
        on **F.Cu**: J5A (pack +), C1 (bulk), and the three high-side drains
        Q1/Q3/Q5. KiCad reports **8 unconnected VM items** -- J5A to Q1, Q1 to
        Q3, Q3 to Q5, Q3 to C1, and the rest. Nothing joins them to each other
        or down to the plane. Top-side VM pads span x 2.20..22.81,
        y 4.60..13.05 mm, so a single **F.Cu VM pour of about 22.6 x 10.5 mm**
        reaches all of them; stitch it to In2 where there is room. Worst-case
        lateral run J5A -> far Q5 drain is ~20.6 mm; at 2 oz that is **5.2 W
        as a 3.0 mm router track vs 0.7 W as the full pour**. The band is
        already reserved for the pack input and the high-side drains, so the
        pour costs no area. **Do not let the autorouter close this.**
        **DONE:** `tools/add_vm_top_pour.py` poured 235.1 mm^2 of VM on F.Cu
        over y 0.60..15.50 at priority 2 (below the phase pours' 3, above the
        F.Cu GND pour's 0), pad connection FULL so no thermal spokes sit in
        series with a 50 A drain. J5A, C1 and all three high-side drains are
        now one piece of copper; 4 of the 8 VM connections closed. The other 4
        are bottom-side low-current taps (U5 supply, R8 sense divider, C6
        decoupling) and are ordinary routing.
        **STILL OPEN -- the pour alone is NOT the finished conductor.**
        Measured on the filled result, it necks to **2.39 mm of copper height
        at x = 17.3 mm**, pinched between J5B (the GND pack terminal,
        y 1.10..8.10) above and the PH_C pour (y >= 11.10) below. That neck is
        the sole F.Cu path to Q5's drain: ~2.2 mm long, ~0.9 squares,
        0.28 mOhm, **0.7 W concentrated in about 5 mm^2** -- a hot spot, not a
        margin. Fix is via stitching to the unobstructed In2 VM plane so the
        neck stops being the sole path. NOT done here because it needs two
        decisions: (a) via count/placement -- ~23 x 0.3 mm vias to match 2 oz,
        with free pour area either side of the neck, versus putting them in
        the drain lands; (b) **via-in-pad is a paid fab option** -- filled and
        capped costs extra, unfilled wicks paste and starves the joint. On
        flight hardware that is the repo owner's call. Also check any new via
        against U5's 12 GND thermal vias directly underneath -- that pair has
        already produced one verified GND-to-VM short on this board.
        REFERRED TO USER.
  - [ ] 12.5.t **(BLOCKING, electrical) THE PHASE GAP -- the phase nets do
        **Status 2026-08-20 — partly addressed, not closed.** The phase pours
        now extend to y 85.50 and reach J4A/B/C (`tools/fix_phase_pours.py`,
        12.5.av(g)). **Connectivity is unproven** because the board is
        unrouted, and 12.5.av recorded the pours fragmenting into 3-4 islands
        each once routing ran. Re-verify with the `kicad` skill's
        `connectivity_graph` after the next successful route.
        not reach their own terminals in copper.** Measured off the board
        2026-08-16: the PH_A/PH_B/PH_C pours are on **F.Cu** and end at
        y = 33.10 mm; their terminals J4A/J4B/J4C are on **B.Cu** starting at
        y = 48.10 mm. Each phase therefore has a **15 mm gap AND a layer
        change** between its pour and its terminal. The x-alignment is
        already correct -- each terminal sits under its own column.
        **This must not be handed to the autorouter.** `tools/autoroute.py`
        puts PH_* in a 3.0 mm "power" class, and at 2 oz a 3.0 mm track
        across this gap dissipates **11.4 W across the three phases -- more
        than all six FETs' conduction loss combined (10.5 W)**, in series
        with the pours' own 6.7 W. Run `docs/tools/conductor_sizing.py`,
        which now models this gap. Three closures, cheapest first:
        (1) **move J4A/B/C to F.Cu and extend each pour down to its terminal**
        -- zero vias, zero added dissipation, but J2 (x 6.0) and J3 (x 18.5)
        currently occupy that top-side band, so it is a PLACEMENT decision
        and the repo owner's call; (2) keep the terminals on B.Cu, add a B.Cu
        phase pour per column and stitch with **23 x 0.3 mm vias per phase**
        (69 total, 2.2 A each) in a region that must also clear U1/U2 and the
        resistor columns; (3) widen to full pour width on B.Cu without a
        matching via count -- easiest to draw, easiest to get wrong, because
        the via field then becomes the narrowest point. **Option 1
        recommended:** 2 and 3 both pay for a layer change the geometry does
        not require. REFERRED TO USER.
  - [~] 12.5.y **Front/back re-placement by the repo owner (2026-08-17).**
        Front now carries power (pack -> FETs -> phase terminals), back
        carries control and comms (U1/U2, U3/U4, J2/J3), comms and pack input
        at the same end. **This opened the F.Cu corridor U3/U4 used to block**
        -- the structural fix for 12.5.t. `tools/fix_after_replacement.py`
        applied the four mechanical consequences: swapped J4A<->J4C (they were
        crossed -- J4A sat at x 21.6 with its FETs at x 2.2-6.0, a 19.4 mm
        span with two 50 A nets having to cross; now 3.8 mm each), pulled 5
        footprints off the board edge, removed 400 stale FreeRouting items,
        and rebuilt the 3 phase pours + the F.Cu VM pour from the pads they
        actually have to reach. DRC 713 -> 63 violations; 0 shorts, 0
        clearance, 0 edge-clearance. Remaining: 43 silkscreen (12.5.u), 12
        drill (12.5.x), 8 starved_thermal on GND.
  - [ ] 12.5.z **(BLOCKING, electrical) The isolation keepout now sits on top
        of the phase terminals.** It is a 4-layer no-copper-pour rule area at
        x 0.85..24.65, y 50.60..59.30 -- placed when the isolated parts were
        at the bottom. They are now at y 0.19..22.77 on the back, so the
        keepout protects nothing and instead blocks the phase pours from
        their own terminals: PH_B is cut clean at y 50.60, and PH_A/PH_C only
        get past through a **0.30 mm strip** along the board edge (x 0.55..0.85
        and 24.65..24.95) that does not even reach the pads. All three phases
        still read 1 unconnected each. **The phase gap is NOT closed until
        this moves.**
        Moving it is not mechanical. The pack input is now at the top
        (y 1.10..8.62) and the FETs are in the middle (y 23.35..44.35), so VM
        has to traverse the band a relocated keepout would occupy. Barrier
        geometry measured 2026-08-17: U3 isolated pins x 1.98 / non-isolated
        x 11.28; U4 isolated x 14.45 / non-isolated x 23.75; both y
        10.38..21.82. A keepout as two narrow edge bands (rather than one
        full-width rectangle) would clear the middle for VM -- but that
        depends on 12.5.aa. REFERRED TO USER.
  - [x] 12.5.aa **J2/U3 isolation RESOLVED 2026-08-17** -- the repo owner
        rotated U3 by 180 deg, putting its isolated row at x 11.28 facing J2.
        The CAN runs are now **0.05 mm and 2.59 mm** (were 9.35 and 11.89).
        U4/J3 was already correct at 0.58/3.12 mm. Original finding kept
        below for the record.
  - [x] 12.5.aa-orig **(was BLOCKING) J2 was on the wrong side of U3 --
        the CAN channel's isolation is defeated.** Measured 2026-08-17:
        U3's isolated pins sit at x 1.98, but J2's pads are at x 11.33..13.87,
        on the far side of U3's own NON-isolated row (x 11.28). The isolated
        CAN conductors therefore run **9.35 mm and 11.89 mm in x**, straight
        across the U3 package and past its non-isolated pins. J3/U4 is fine by
        contrast (0.58 and 3.12 mm, directly adjacent to U4's isolated row).
        Fix is either mirroring U3 so its isolated row faces J2, or moving J2
        to the left edge beside U3's isolated pins. Which one is chosen sets
        the keepout shape in 12.5.z, so decide these two together.
        REFERRED TO USER.
  - [~] 12.5.ac **(electrical) ISOLATION CREEPAGE — board widened to 32 mm
        2026-08-19; the U1 half is CLOSED, the pack-versus-comms half is not.**
        `tools/widen_board_to_32mm.py` took the board **25.40 -> 32.00 mm**
        (length unchanged at 60.10). U1 is centred and U4 re-anchored to the
        new right edge. **U1's closest approach to an isolated conductor went
        4.27 mm -> 9.50 mm** (U3.11 <-> U1.48), clearing the 7.5 mm
        requirement with 2.0 mm spare.
        The power stage did not move and did not need to: SH1 is a Wurth
        WE-SHC 3670209 [51] with a fixed 22.2 mm land that must sit under the
        FETs, so the FET columns are capped at the shield width however wide
        the board gets. Every added millimetre went to the isolated section
        and U1 — which is what needed it.
        **STILL OPEN — the pack terminals and the isolated comms share the top
        end:**
            J2.1  <-> J5A.1   4.35 mm
            J3.2  <-> J5B.1   4.83 mm
            U3.20 <-> J5A.1   6.35 mm
        Widening cannot fix this: J5A spans x 1.10..8.10 and J5B x 17.60..24.60,
        overlapping in x with where both isolated groups must live, so they can
        only separate in Y. The options remain as recorded below — (a) pack
        terminals to the bottom beside the phase terminals, (b) isolated
        section to the bottom, (c) accept the added length. REFERRED TO USER.
        **Also outstanding from this move:** U1's new centred position overlaps
        J1 and several of the parked isolated capacitors (58 electrical DRC
        violations). Those parts were already outside [9]'s 10 mm lead-length
        limit and were always going to be re-placed — 12.5.af.
  - [x] 12.5.ac-orig **(was BLOCKING) the constraint set was over-determined
        at 25.4 mm width.** Repo owner's decision 2026-08-18: **do not weaken the
        isolation.** Reason recorded verbatim, because it should not be
        silently revisited — "the whole reason for isolation and an emi shield
        is that this board is designed to survive harsh emi environments,
        which is also why it has redundant control paths. so weakening its
        design isn't the correct course." The IEC 60664-1 route (deriving a
        smaller creepage from a lower system working voltage) is therefore
        CLOSED. 7.5 mm per [9] Table 6 stands.
        **Arithmetic established 2026-08-18, U1 half:** with U3/U4 rotated so
        both isolated rows face the board edges (x 1.98 and x 23.75), the
        7.5 mm exclusions leave only x 9.48..16.25 = 6.77 mm of legal
        non-isolated width, and U1 is 13.45 mm wide -- so U1 cannot sit
        beside the isolated section at any x and must clear it in y. Centred,
        U1's top must reach y >= 27.63 (binding pad U3.11 at (1.98, 21.32),
        dx 4.04), a 4.76 mm move down; SH1 cannot absorb it because it is
        locked under the FETs. Rounded to 4.80 mm, the board goes
        60.20 -> 65.00 mm. `tools/grow_board_for_creepage.py` implements this.
        **NOT APPLIED, because it does not finish the job.** Running it and
        re-measuring showed creepage still fails, now against the PACK
        TERMINALS rather than U1:
            J2.1  <-> J5A.1   4.35 mm
            J3.2  <-> J5B.1   4.83 mm
            U3.20 <-> J5A.1   6.35 mm
            U4.11 <-> J5B.1   6.36 mm
        The 50 A pack input and the isolated comms section both live at the
        top of the board, overlapping in x (J5A spans x 0.73..9.28; U3's
        isolated group must live at x ~2). They can only separate in y, and
        J5A's bottom edge at y 8.62 would push the isolated section down to
        y >= 16.12 -- about 7 mm, on top of U1's 4.8 mm. That is ~72 mm of
        board, past the original 70 mm target.
        **This is an architecture question, not a length question:** the pack
        input and the isolated section cannot share the top end. Options:
        (a) pack terminals move to the bottom beside the phase terminals --
        VM then runs the board length, ~1.9 W at 50 A across the In2 plane at
        full width, which is tolerable; (b) the isolated section moves to the
        bottom -- gives up the same-end wiring convenience that motivated the
        current arrangement; (c) accept ~72 mm of board length. REFERRED TO
        USER.
  - [x] 12.5.ac-orig **(was BLOCKING) creepage measured 3.49 mm against a
        7.5 mm requirement.** [9] Table 6 (verified 2026-08-17 in
        `docs/datasheets/analog-devices-adm2582e-adm2587e-datasheet.pdf` p.5)
        specifies **7.5 mm minimum external air gap (clearance) AND 7.5 mm
        creepage, measured input terminals to output terminals**, with
        footnote 2: "Consideration must be given to pad layout to ensure the
        minimum required distance for clearance is maintained." Measured on
        the 2026-08-17 placement, closest isolated-to-non-isolated pads on a
        shared layer, different parts:
          U4.11 (isolated) <-> U2.10  **3.49 mm**
          U4.11 (isolated) <-> U2.9     3.97 mm
          U4.11 (isolated) <-> U1.1     4.58 mm
        The board therefore undercuts the transceiver's own 5 kV rating --
        the barrier is only as good as its weakest external gap. U1 (MCU) and
        U2 (OPTIGA) need to move about 4 mm further from U4's isolated row,
        or the transceivers need to move. PLACEMENT CALL. REFERRED TO USER.
  - [x] 12.5.ad **DONE 2026-08-17 -- isolated-supply ferrites fitted, and
        they turned out to be fixing a BROKEN SUPPLY, not adding EMC polish.**
        Reading [9] p.8 and [10] p.15 pin tables showed the isolated side of
        both transceivers was simply unwired: `CAN_VISOOUT` reached only
        U3.19, `CAN_VISOIN_OPEN` only U3.16, `RS485_VISOOUT` only U4.12,
        `RS485_VISOIN_OPEN` only U4.19 -- all dangling. Both datasheets
        require VISOOUT to feed VISOIN ([10]: "Connect this pin through a
        ferrite bead and short the PCB trace to VISOIN **for operation**";
        [9]: "This pin must be connected externally to VISOIN"). It did not,
        so neither bus side had a supply at all. Both also had their isolated
        grounds MERGED where the datasheets require a ferrite split, and [9]'s
        pin-16 entry says outright "Ground, Bus Side. **Do not connect this
        pin to Pin 14 and Pin 11**" -- the pre-existing net merged exactly
        those pins.
        Fitted four Murata BLM15HD182SN1D [53] (1800 Ohm @100 MHz / 2700 Ohm
        @1 GHz, meeting [9] p.17's "approximately 2 kOhm between the 100 MHz
        and 1 GHz frequency range"; the part [10] Table 12 names by number for
        this role). `tools/add_isolated_supply_ferrites.py` (schematic) and
        `tools/add_ferrites_to_pcb.py` (PCB). Resulting topology:
          FB1  CAN_VISOOUT(U3.19)   -- CAN_VISOIN(U3.16)
          FB2  CAN_GNDISO(U3.18,20) -- CAN_ISO_GND(U3.11,12,15)
          FB3  RS485_VISOOUT(U4.12) -- RS485_VISOIN(U4.19)
          FB4  RS485_GNDISO(U4.11,14) -- RS485_ISO_GND(U4.16,20)
        **ERC 0 errors** (was 0, but `CAN_VISOOUT`/`RS485_VISOOUT` dangling
        warnings are now gone); **DRC 0 electrical violations.** Current
        rating checked, not assumed: [53] rates 200 mA / 2.2 Ohm max DCR, and
        the beads carry only isolated-side transceiver current -- [9] Table 14
        confirms the ADM2582E has "no current available externally on
        VISOOUT". Correction recorded: an earlier note in this file claimed
        the ADM3055E did not want ferrites. It does ([10] p.25, "filter both
        the VISOOUT power supply pin and GNDISO power supply return pin ...
        Use surface-mount ferrite beads in series"); what [10] says is NOT
        required is stitching capacitance and HV safety capacitors.
  - [~] 12.5.af **(placement, WITH THE REPO OWNER) The isolated section's
        twelve support parts are on the board and PARKED OFF-BOARD for hand
        placement** (2026-08-17, at the repo owner's request). All twelve now
        exist and are netted: FB1-FB4 [53] in a staging column at x = 32 mm,
        C11-C18 at x = 40 mm, both outside the 25.45 mm board outline.
        **ERC 0 errors, DRC 0 electrical violations.** Capacitor values and
        pin pairings are quoted, not chosen: [10] p.15 pin 19 "requires
        0.22uF and 10uF capacitors to GNDISO" and pin 16 "requires 0.01uF and
        0.1uF decoupling capacitors"; [9] p.17 "0.1 uF and 10 uF for VISOOUT
        at Pin 11 and Pin 12 ... 0.01 uF and 0.1 uF ... for VISOIN at Pin 19
        and Pin 20". Package (0805) and voltage rating are AGENTS.md Sec.4
        engineering defaults matching C2..C10; no MPN is claimed for the
        capacitors -- none has been selected.
        **When placing, the two isolated grounds are NOT interchangeable:**
        the VISOOUT reservoirs return to the dc-to-dc converter ground
        (CAN_GNDISO / RS485_GNDISO), the VISOIN decouplers to the bus-side
        ground (CAN_ISO_GND / RS485_ISO_GND), and the beads bridge the two.
        Constraints to honour: [10] p.15 "short the PCB trace to VISOIN";
        [9] p.17 "total lead length between both ends of the capacitor and
        the input power supply pin should not exceed 10 mm"; and [9]'s
        ordering "the C1 capacitor connects between VISOOUT (Pin 12) and GND2
        (Pin 11) on the device side of the L1 and L2 ferrites".
        Still needs room: U3's isolated pin row is at x 11.28 and U4's at
        x 14.45, 3.17 mm apart with a 0.55 mm channel between courtyards,
        J2/J3 above and U1/U2 below. The same move also fixes 12.5.ac
        (creepage 3.49 mm against 7.5 mm required).
  - [x] 12.5.af-orig **(was BLOCKING) The isolated section had no room for
        its own support components.** The four beads are on the board with
        correct nets but are PARKED at x 19.4..24.9, y 24.5..28.6 -- the only
        free back-side pocket -- 9.3 to 16.9 mm from the pins they serve,
        against [10] p.15's "short the PCB trace to VISOIN". There is nowhere
        closer: U3's isolated pin row is at x 11.28 and U4's at x 14.45,
        facing each other across 3.17 mm, with the two courtyards (U3 to
        12.59, U4 from 13.14) leaving a 0.55 mm channel. Everything else
        adjacent is J2/J3 above and U1/U2 below.
        Worse, the datasheets also require **eight capacitors** this board
        does not have: [10] wants 0.22 uF + 10 uF on VISOOUT to GNDISO and
        0.01 uF + 0.1 uF on VISOIN; [9] wants 10 uF + 0.1 uF on VISOOUT and
        0.1 uF + 0.01 uF between pins 19 and 20 -- and [9] fixes their
        position relative to the beads ("the C1 capacitor connects between
        VISOOUT (Pin 12) and GND2 (Pin 11) on the device side of the L1 and L2
        ferrites"). Twelve parts total need a channel along both isolated pin
        rows. This compounds 12.5.ac (creepage 3.49 mm vs 7.5 mm required),
        which also wants U1/U2 moved away from U4. Both are solved by the same
        move. REFERRED TO USER.
  - [x] 12.5.ad-orig **(was High, EMC) The ADM2582E's recommended L1/L2
        ferrites are absent from the design.** [9] "PCB Layout and Electromagnetic
        Interference (EMI)" (p.17) instructs: "filter both the GND2 pins
        (Pin 11 and Pin 14) and VISOOUT signals of the integrated dc-to-dc
        converter for high frequency currents. Use surface-mount ferrite
        beads in series with the signals before routing back to the device",
        impedance ~2 kOhm over 100 MHz-1 GHz, to suppress the 180 MHz
        primary and 360 MHz secondary switching harmonics; Figure 35 is the
        recommended layout. The board carries **no ferrites at all** --
        reference designators present are only J, U, R, Q, C, SH. This is a
        schematic/BOM gap, not a layout one, and it matters directly to the
        Faraday EMI tier. Note the ADM3055E (CAN, [10] p.25) states the
        opposite for itself: "Neither PCB stitching capacitance nor high
        voltage surface-mounted technology (SMT) safety capacitors are
        required" -- so this applies to the RS-485 part, U4.
  - [~] 12.5.ae **PARTLY RESOLVED 2026-08-31 — inner layers stripped.**
        Option (b)'s inner-layer half is done: In1.Cu/In2.Cu removed from the
        rule area by `tools/restore_inner_planes.py`, restoring the
        plane-to-plane overlap [9] p.17 asks for. **Still open:** whether the
        remaining F.Cu/B.Cu scope should be deleted (option a) or shrunk to
        the U3/U4 package bodies (option b) — that moves 50 A current paths
        and still needs sign-off. Original entry follows.
        **(Medium) The isolation keepout is not datasheet-driven and
        should be replaced, not relocated.** The existing rule area is a
        full-width, 4-layer no-copper-pour rectangle. [9] p.17 asks for the
        **opposite** on a 4-layer board: "place an embedded stitching
        capacitor between GND1 and GND2 using internal layers of the PCB
        planes. An embedded PCB capacitor is created when two metal planes in
        a PCB overlap each other and are separated by dielectric material.
        This capacitor provides a return path for high frequency common-mode
        noise currents across the isolation gap." The **only** keepout [9]
        specifies is narrow and conditional: "there must not be a GND2 fill
        on any layer below the L1 and L2 ferrites" -- i.e. a keepout of the
        ISOLATED ground fill around ferrites this design does not yet have
        (12.5.ad). So the full-width cut removes the plane overlap AD wants,
        while the constraint that actually binds is creepage (12.5.ac).
        Two options, both needing sign-off:
        (a) delete the rule area and rely on creepage + the stitching-
            capacitor plane overlap, per [9];
        (b) keep a cut but shrink it to the U3/U4 package bodies between the
            pin rows, and drop F.Cu from its layer set -- F.Cu is the far
            face, 1.6 mm of FR4 from the B.Cu isolated pads, and it is the
            layer VM must cross to get from the top-end pack to the
            mid-board FETs.
        Either way the current rectangle must go: it sits at y 50.60..59.30,
        on top of the phase terminals, where it blocks all three phase pours
        (12.5.z) and protects nothing.
  - [ ] 12.5.ab **(High, electrical) Two constraints regressed in the
        re-placement.** Measured before -> after:
        **shunt to sense amp 1.2/2.6/2.6 mm -> 28.0/22.0/28.0 mm** (millivolt
        differential taps across a 0.5 mOhm shunt, now running the length of
        the board past three switching nodes -- the README constraint was
        "each sense amp under its own shunt"); and **C1 to high-side drain
        4.1/7.1/9.7 mm -> 17.6/23.6/24.0 mm**, the commutation loop the 40 V
        FET choice on a 25.2 V pack depends on. Per the README's own table a
        ~20 nH loop leaves only IDRIVE <= 300 mA under 40 V, and that lands at
        38.2 V -- under 5% margin. Gate loops also stretched to 3.8-13.9 mm
        (Q3 worst) from U5 sitting directly under the array. All three are
        placement calls. REFERRED TO USER.
  - [ ] 12.5.ag **(High, security) Permanent write/debug lock — use the MCU's
        internal capability, NOT a board-level fuse** (repo owner's decision,
        2026-08-18). The board keeps a plain 4-pad SWD probe pattern at J1
        (12.5.ah); **no fusible link, solder-bridge or series fuse is added**.
        Rationale: a board-level fusible link is re-bridgeable by anyone who
        can solder, so it provides tamper-evidence rather than a seal. The
        MSPM0G3507's own one-time configuration is the only irreversible
        option, and it costs no board area.
        **Verified locally from [1]** (`docs/datasheets/mspm0g3507.pdf`, read
        2026-08-18): §8.33 p.73 — "Access to the device memory and
        configuration through the BSL is protected by a 256-bit user-defined
        password, and it is possible to completely disable the BSL in the
        device configuration, if desired. The BSL is enabled by default from
        TI." §7 memory map — the NONMAIN configuration NVM sits at
        0x41C0.0000–0x41C0.0200 (512 bytes), separate from main flash, and is
        where boot/debug configuration lives.
        **NOT verified locally, and required before implementation:** the
        register-level debug-disable mechanism. [1] §8.32 p.73 defers it
        entirely — "For a complete description of the debug functionality
        offered on MSPM0 devices, see the debug chapter of the technical
        reference manual." That manual is [54] and **is not in
        `docs/datasheets/`**. Obtain it, then specify: which NONMAIN field
        sets the debug policy, whether the permanent state is genuinely
        one-way, the interaction with the 256-bit BSL password, and the
        production sequence (program → verify → seal), since sealing before a
        verified image is unrecoverable.
        Note the ordering constraint against 12.5.b/12.5.q: the lock must be
        the LAST production step, after the IDRIVE bench measurement and any
        firmware trim, or the board is bricked for tuning.
  - [x] 12.5.ah **J1 shrunk to a 1.27 mm probe pattern** (2026-08-17),
        `SolderPad_1x04_SMD_P1.27mm_Probe`: 9.22 x 3.20 mm / 36.0 mm^2 ->
        4.71 x 1.80 mm / 12.0 mm^2. J1 is SWD only (SWDIO/SWCLK to U1.12/13
        plus 3V3 and GND) and is a bring-up interface, not a flight
        connection, so it does not need J2/J3's wire-solder pad area. 1.27 mm
        is the standard pogo-jig pitch; single-row keeps the fixture trivial.
        Rejected: Tag-Connect TC2030 — its three through-board alignment holes
        cost their area on both sides, a net loss here. J2/J3 keep the 2.54 mm
        wire variant (12.5.k).
  - [x] 12.5.ai **50 A RATING VALIDATED against the load it actually drives**
        (2026-08-18). The airframe this build feeds — Serenity-UAV — turns
        four XFly Galaxy X5 50 mm 12-blade 6S EDFs, two per nacelle, each
        with its own ESC. Manufacturer figures [55]: **38 A draw, 843 W,
        1240 g thrust, recommended ESC 50 A**, with the note "The controller
        should be chosen 20% over rated due to the long lasting load."
        38 A x 1.20 = 45.6 A, so **50 A is the manufacturer's own answer and
        this build matches it at 1.32x the draw.** 843 W / 22.2 V = 38.0 A
        confirms the figures are self-consistent. Four fans draw 152 A / 3372 W
        from the pack in total.
        This closes a spread that looked alarming: the Serenity archive
        `docs-superseded/POWER_SYSTEM_Q.md` carries 55 A peak (L241) and
        84 A peak / 55 A continuous (L248) for these fans, recommending 60 A
        and 120 A ESCs. Those are superseded and do not match the fan's own
        published 38 A. Every figure sized in this repo against 50 A — the
        TPHR8504PL choice, the 0.5 mOhm shunts, the 7.5 mm phase pours, the
        2 oz copper floor — stands.
  - [ ] 12.5.aj **(Medium, cross-repo) Serenity-UAV's own ESC line is
        under-spec and still names a different part.** `airframe/README.md`
        L57 and `TODO.md` L546 specify **40 A BLHeli32** ESCs for these fans.
        Against [55] that is 40/38 = **1.05x the draw**, well under the
        manufacturer's own 20% margin rule, where this build's 50 A gives
        1.32x. Two further notes for that repo, found while checking:
        (a) the BOM specifies **BLHeli32**, whose control path is DShot —
        replacing those units with Open-Secure-ESC moves command onto CAN-FD
        or RS-485, and DShot is not on this project's protocol axis at all;
        (b) `airframe/README.md` L57 budgets "battery + PDB + ESCs" at ~500 g
        while its own §4.3 puts the two batteries alone at 1,180 g;
        (c) [55] gives the EDF unit mass as **75 g**, not the 70 g in
        `bom_revS.json` — 4 x 75 = 300 g, not 280 g, which bears on the
        EDF-mass discrepancy already open in that repo's
        `SPEC_VERIFICATION_0.6.1.md`. Raise upstream; not actionable here.
  - [x] 12.5.ak **Two isolation placement rules encoded as harness checks**
        (2026-08-19, repo owner's direction: "commit these details to the
        harness for all future boards"). Both now pass/fail in
        `tools/score_placement.py`, and written up in
        `docs/solutions/architecture-patterns/isolation-geometry-sets-board-aspect.md`
        because the harness is build-local and the doc is what reaches a
        future board:
        (a) **an isolating IC's pin rows must run ACROSS the board's long
        axis**, so its isolated side faces a short edge. Isolated copper near
        a long edge poisons that edge for the board's whole length on both
        faces; rotating the transceivers 90 deg moved the nearest isolated
        copper from 0.72-0.82 mm off the side edges to ~2.94 mm and relaxed
        the required opposite-inset from 5.08 mm to 2.96 mm.
        (b) **pack terminals must not share a copper layer with the isolated
        section.** A through-hole terminal spans every layer and always makes
        an in-plane creepage pair; SMD on the opposite face leaves only the
        longer around-edge path -- worth 2.80 -> 4.64 mm on its own.
        Both regression-tested by deliberate violation: (a) reports
        "PARALLEL, rotate 90" per IC, (b) names the offending refs. Neither is
        scored -- a violation is an arrangement that cannot be nudged into
        compliance.
  - [x] 12.5.al **CORRECTED AND RESOLVED — creepage is 7.83 mm with 0.33 mm
        of margin. The "ceiling" was a bug in the harness, not the board.**
        The original entry claimed 7.51 mm was structural and could only be
        improved by widening the board. That rested on `edge_path()` computing
        `insetA + thickness + insetB`, which assumes two opposite-face parts
        sit at the same position ALONG the edge. They rarely do. U3 against Q2
        are ~26 mm apart in y, so the true unfolded path is 27.15 mm, not the
        7.83 mm being reported. Corrected to
        `sqrt(along_edge_sep^2 + (insetA + T + insetB)^2)`.
        With that fixed the FETs stop being binders at all — every
        around-edge pair sits at 7.98 mm or better — and the only real
        constraint is the in-plane U3.20 <-> U4.10 pair, which spreading the
        two transceiver groups relieves. The size of the safe step was itself
        overstated on the first pass and is corrected here:

        | spread   | creepage | DRC-el | unconnected |
        |----------|----------|--------|-------------|
        | +/-0.00  | 7.51     | 0      | 159 (base)  |
        | +/-0.25  | 7.66     | 0      | 159         |
        | +/-0.50  | 7.83     | 0      | 159 APPLIED |
        | +/-0.75  | 7.98     | 0      | 160         |
        | +/-1.00  | 7.98     | 0      | 161         |

        **+/-0.5 mm is the largest spread that costs nothing**: creepage
        7.51 -> 7.83 mm, isolated lead unchanged at 9.76 mm, no new broken
        nets. +/-0.75 and +/-1.0 buy a further 0.15 mm by SEVERING GND
        connections — refilling the pour around the moved parts fragments the
        B.Cu GND pour, and two of the casualties are on U5, which never moved.
        Revisit that extra 0.15 mm only with deliberate GND stitching.
        **Three claims in the original entry were wrong and are withdrawn:**
        that the FET columns must stay within SH1's 22.20 mm land (they
        already overhang it — Q1/Q2 by 0.75 mm, Q5/Q6 by 2.75 mm, with 5.30
        and 6.30 mm of inter-column slack); that more board width was the only
        lever; and that +/-1.0 mm was clean, which held only because the
        harness was not counting broken connections. None survived checking.
  - [x] 12.5.am **WITHDRAWN — the claim was false and the board is fine.**
        This item asserted that none of the 59 footprints carried a courtyard
        and that every courtyard-clean DRC result was therefore vacuous. Both
        halves were wrong, and the cause was a one-line bug in the check, not
        anything on the board.
        The check tested `"CrtYd" in board.GetLayerName(layer)`. In KiCad 9
        `GetLayerName()` returns the **display** name, which is
        `"F.Courtyard"` / `"B.Courtyard"` — the canonical `F.CrtYd` string
        never appears in it, so the test could not match and reported 0 of 59.
        Verified three ways 2026-08-19: comparing `GetLayer()` against the
        `pcbnew.F_CrtYd`/`B_CrtYd` layer IDs gives **59 of 59**; the raw
        `.kicad_pcb` contains 306 `CrtYd` lines; and all 16 distinct source
        footprints (11 KiCad system, 5 `Open_Secure_ESC.pretty`) carry
        courtyards.
        The DRC rules are live, not suppressed: `.kicad_pro` sets
        `courtyards_overlap` = **error** and `malformed_courtyard` = **error**,
        and both report zero. (`missing_courtyard`, `pth_inside_courtyard` and
        `npth_inside_courtyard` are set to `ignore`, which is worth a
        deliberate decision but is not what this item claimed.)
        Lesson for future checks: compare layers by **ID**, never by
        substring of a display name. `tools/restore_courtyards.py` was written
        against this false premise and has been deleted.
  - [~] 12.5.an **PARTLY RESOLVED, and one claim in the original corrected.**
        The board has exactly one *authored* rule area — board-local
        x 0.85..31.25, y 56.60..65.30, all four copper layers — prohibiting
        `copperpour` only. It does clip the phase pours: PH_A/B/C fills stop
        at y 56.60 while the J4A/B/C pads span y 55.60..65.60, so pour meets
        pad over 1.00 mm of a 10 mm pad, and a 0.3 mm strip of each phase
        fills separately past y 65.30.
        **Correction:** the original entry called those strips "stranded" and
        blamed them for the 2 `isolated_copper` warnings. Wrong on both
        counts — each strip is connected through its own J4 terminal pad, and
        DRC never flagged them. The real isolated fill was a **4.313 mm² VM
        pocket on In2.Cu** inside U5's thermal-via ring, fenced off by the
        via clearance cutouts on three sides and the VM zone's own y = 40.60
        lower boundary on the fourth, with nothing on net VM inside it —
        a floating plate under a switching gate driver.
        `tools/remove_vm_island.py` excludes it with a scoped In2.Cu rule
        area. The zone's `island_removal_mode` was already `ALWAYS` and did
        not remove it; a clean reload-fill-save cycle reproduced it, so this
        was not the stale-fill trap. `isolated_copper` 2 -> 1.
        **Answered 2026-08-31 for the inner layers:** it was NOT intended
        there. The rule area was authored when U3/U4 sat at that end; they
        are now at y 34.50 on B.Cu, so it guarded nothing while cutting both
        GND planes across the full board width. In1.Cu/In2.Cu stripped by
        `tools/restore_inner_planes.py`; the In2.Cu VM-island rule area is
        the one justified inner-layer keepout and was kept.
        **Still open:** whether the remaining F.Cu/B.Cu scope over the phase
        terminals is intended (see 12.5.ae), and identify the last remaining
        `isolated_copper` (1, warning).
  - [x] 12.5.ao **DONE 2026-08-19 — 11 starved GND thermals given solid zone
        connections.** `.kicad_pro` sets `min_resolved_spokes = 2`; these pads
        each resolved one, hanging off the GND pour by a single 0.5 mm neck.
        `tools/fix_starved_thermals.py` set them solid. A spoke cannot be
        conjured where the pour does not reach, so widening spokes or
        shrinking the thermal gap would not have helped.
        It is also the better design here rather than merely the expedient
        one: this board carries galvanic isolation, redundant control paths
        and a Faraday shield specifically to survive harsh EMI, and shield
        effectiveness is set by the impedance of the ground bond — SH1 bonded
        through one narrow spoke is mostly inductance. Same repo precedent as
        `add_vm_top_pour.py`.
        **DECIDED 2026-08-19 — repo owner specified professional reflow
        assembly, so all 16 pads KEEP their solid
        connections and `--skip-passives` is NOT to be used on this build.**
        A controlled reflow profile handles a solid 0805 GND bond; the relief
        was only ever worth it to protect hand-soldering and rework. The
        original trade is kept below for the record.
        **Assembly trade, as it stood before that decision:** solid pads sink heat during
        reflow. The 9 IC/shield pads (SH1 x4, U5.25, U6.1/.2, U8.1/.2) are
        low risk. The 5 two-terminal 0805 passives (**C7 C9 C10 R5 R10**) are
        the tombstoning-asymmetry case — 0805 is far more forgiving than
        0402/0201, but if this board is to be hand-soldered or reworked, run
        `tools/fix_starved_thermals.py --skip-passives` to leave those five
        on thermal relief and accept their 5 warnings.
        C7 only appeared on the second pass: solid-bonding the first ten
        changed the pour around it enough to drop it from two spokes to one.
        Zone fills are coupled, so this class of fix is iterated to a fixed
        point. `starved_thermal` 11 -> 0.
  - [x] 12.5.as **DONE 2026-08-19 — U1, U5 and SH1 centred by the repo owner;
        two follow-on defects found and fixed.** The owner moved U1 and U5
        with their surrounding components +1.000 mm in x, putting U1, U5 and
        SH1 all exactly on the centreline (x = 16.000). This is the move
        `symmetrize.py` had REFUSED (DRC electrical 1 and 28) — the guard was
        right about the tool's version, which moved the ICs *alone*; moving
        each IC together with its supporting parts is a different move and it
        passes cleanly.
        As saved it showed 155 errors, **all of them stale zone fill**. After
        a refill: 0 errors. (Same lesson as the J5B move — a GUI part move
        leaves the fill stale; refill before judging.)
        **Real cost, accepted by the owner:** the worst gate loop grew
        16.53 -> 17.36 mm, because centring the driver moves it away from
        phase A. Measured per-phase driver-pad-to-gate-pad distance is now
        Q1 12.17 / Q2 13.73 / Q3 6.85 / Q4 5.89 / Q5 14.30 / Q6 14.86 mm —
        note centring did **not** balance A against C (they still differ by
        ~1.5 mm), because U5's gate pads are not symmetric on the package.
        Worth revisiting if switching performance on phase C matters.
        **Follow-on 1 — `remove_vm_island.py` had a stale hardcoded box.**
        It carried the island extent as a literal rectangle measured once.
        When U5 moved, the via ring went with it and the rule area did not,
        letting a 1.117 mm² sliver of VM plane escape through exactly the
        millimetre no longer covered. Now DERIVED from U5.41's actual via
        positions every run, so it follows U5 anywhere. *A constant that
        describes another object's position goes stale the moment that object
        moves.*
        **Follow-on 2 — `tools/close_edge_orphans.py` (new).** The authored
        phase-terminal rule area stopped at y 85.20 while the board outline
        runs to 86.05. Pour refilled that 0.85 mm gap and, cut off from
        everything above by the rule area itself, formed orphan strips along
        the bottom edge on every layer — including 8.747 mm² of GND on In2.Cu
        running the full board width, a floating conductor on a board built to
        survive harsh EMI. Rule area extended 0.5 mm past the edge; orphan
        polygons 18 -> 14. The three phase strips were never a problem (each
        connects through its own J4 pad), confirming the correction already
        recorded in 12.5.an.
  - [~] 12.5.au **Assembly prep for professional reflow, 2026-08-19.
        `tools/prep_for_assembly.py`. NO VENDOR CHOSEN** — the repo owner
        specified "JLCPCB or another similar manufacturer", so this build
        targets the capability envelope mainstream prototype-assembly houses
        have in common, not any one vendor's spec.
        Three defects found and fixed:
        (a) **J1, J2 and J3 would have reached the placement machine.** They
        are bare wire/probe landing pads, like J4A/B/C and J5A/B — but unlike
        those they were NOT flagged `exclude from BOM` / `exclude from
        position files`, so they would have appeared as parts to buy and
        place. Now flagged to match.
        (b) J5A/J5B carried no SMD/THT attribute (leftover from
        `convert_j5_to_smd.py`, which changed the pads but not the attribute).
        Set to SMD.
        (c) **No fiducials existed, on either side, on a DOUBLE-sided
        assembly** (18 footprints F.Cu, 41 B.Cu) carrying a 0.5 mm pitch
        WQFN-40 and a 0.5 mm pitch LQFP-64. Added 3 per side, non-collinear so
        rotation is resolvable, at corner sites with a 2.2 mm clear radius;
        excluded from BOM and position files. DRC unchanged at 17 warnings.
        **OPEN — needs a verified source before ordering (AGENTS.md §3):**
        no vendor capability document has been read, because no vendor has
        been chosen. 3 × 1 mm copper with 2 mm mask opening is ordinary
        industry practice, not a sourced requirement from any house. Once the
        manufacturer is picked, check its published policy and record it in
        REFERENCES.md with a validated URL.
        **Also open for the fab order:** `docs/tools/conductor_sizing.py`
        argues 2 oz copper minimum for the 50 A phase pours; the order must
        specify that explicitly, and 4-layer 2 oz is a non-default stackup
        that needs confirming with whichever house is chosen. REFERENCES.md
        carries the board's tightest features as a table for checking against
        any candidate vendor.

  - [ ] 12.5.at **(Low) Two `isolated_copper` warnings remain, unexplained.**
        **Verified 2026-08-20: still exactly 2 `isolated_copper`** on the
        current board.
        kicad-cli reports one on `Zone [VM] on In2.Cu` and one on
        `Zone [GND] on In2.Cu`, but neither zone fills as more than one
        polygon — checked directly via `GetFilledPolysList().OutlineCount()`,
        which returns 1 for both. So the polygon-count method that found and
        fixed the earlier islands does not reproduce these, and the cause is
        not yet understood. Both are warning severity with DRC electrical at
        0, so this is not fab-blocking. Needs a look in the KiCad GUI, where
        the violation can be selected and located directly. Do not guess at a
        fix; the last two "obvious" island explanations on this board were
        both wrong.

  - [x] 12.5.ap **DONE 2026-08-19 — rows and phase columns aligned.**
        `tools/align_rows_columns.py`. Every target is a position the board
        already used; a part >0.6 mm off its group is read as intent, not
        slip, and left alone. Each move is applied, refilled, scored and
        REVERTED unless DRC electrical stays 0, unconnected does not rise,
        creepage does not fall, and gate/commutation loops do not grow.
        **The majority row is not automatically the right row.** The first
        version snapped outliers to whatever position most of the group
        shared; on the high-side FETs that moved Q1 up to join Q3/Q5, pulling
        it away from U5 and lengthening the worst gate loop 16.49 -> 16.74,
        so the guard reverted it and the row stayed crooked. The right move
        was the opposite — bring Q3/Q5 DOWN to Q1 — which aligns all six FETs
        AND shortens the commutation loop 19.60 -> 19.40. The tool now scores
        every distinct position a group occupies, not just the popular one.
  - [x] 12.5.aq **DONE 2026-08-19 — board made left/right symmetric.**
        `tools/symmetrize.py`. Centreline is **x = 16.000** from the true
        outline polygon; `GetBoardEdgesBoundingBox()` says 32.100 because it
        measures the outer edge of the 0.05 mm Edge.Cuts stroke, which would
        have put the centreline at 16.050 and every pair 0.05 mm off-grid.
        Both halves of a pair shift by the same delta, so separations set by
        hand survive exactly and only the midpoint moves.
        **Result: 12/12 mirror pairs symmetric, phase pitch 10.500/10.500,
        phase B exactly on the centreline, 0 parts off the 0.5 mm grid in x.**
        Two bugs caught in the tool before it ran: `group_x` used the mean, so
        R2's deliberate +0.5 offset would have parked phase B at 15.900 and
        called it centred (now median); and deltas were snapshotted up front,
        so the "R2 alone" job would have used a stale number after phase B
        moved (now recomputed per move).
        **Symmetry and grid conflict unless a pair's separation is a whole
        millimetre** — centring splits it in half, so 8.500 apart becomes
        +/-4.250. Centring alone dropped grid adherence 83.1% -> 44.1%.
        Fixed by rounding each half-separation to 0.5 mm, preferring the
        SAFE direction: pack terminals went outward 8.500 -> 9.000 (more
        pack+/pack- clearance, not less). "iso caps outer" outward pushed the
        isolated lead to 10.03 mm, over the limit, so the guard took inward
        instead — which improved the lead to 9.76 mm.
        **Refused and left off-centre:** U5+SH1 and U1, both needing +0.950 mm
        (DRC electrical 1 and 28). They were grid-snapped 0.05 mm instead.
        The left and right stacks are different circuits, not a mirrored pair.
  - [x] 12.5.ar **DONE 2026-08-19 — U7/U8 swapped onto their own phases.**
        Found while mapping parts to phases for 12.5.aq: every part sat on its
        own phase column except the two sense amplifiers. U8 stood in the
        phase-B column carrying `ISENSE_C_HI`; U7 stood in phase C carrying
        `ISENSE_B_HI`. FETs and shunts were all consistent (Q2/R1 = A,
        Q4/R2 = B, Q6/R3 = C) — only the amps were crossed.
        Not merely untidy: this is a millivolt-scale shunt signal running
        beside half-bridge nodes slewing 25.2 V, and crossed placement forced
        each pair across a phase column to reach its own shunt — longer
        differential loop, more pickup from the node being measured.
        `tools/swap_u7_u8.py` exchanges the two positions. Nets NOT edited —
        the parts move to match the wiring, so the schematic stays
        authoritative. Cost measured at zero: unconnected, creepage, both
        loops and DRC all unchanged (they were not yet routed).
        Follow-on: U7 then inherited the starved-thermal position and was
        added to `fix_starved_thermals.py` — the starvation belongs to the
        POSITION, not the part, so all three sense amps are now listed.

  - [ ] 12.5.w **(BLOCKER for fabrication) The board is NOT ROUTED. This
        **Verified 2026-08-20: still true, and now deliberate.** 151 unrouted.
        The route was cleared rather than committed because the shield-ring
        part moves invalidated it. Blocked on 12.5.bf.
        entry previously overstated the state and is corrected here.**
        It claimed "352 segments, 48 vias, 57 open" from the FreeRouting run.
        Measured 2026-08-19, the board carries **0 track segments, 2 vias and
        157 unconnected items.**
        Traced through history: commit `15eeaa4` ("Route the signal nets")
        did have 352 segments and 49 vias. The very next commit, `8f4791a`
        ("Repair the front/back re-placement"), dropped it to 0 segments and
        1 via — `fix_after_replacement.py` removed ALL routing, not only the
        stale segments its message described. The board has been fully
        unrouted since, through every session that followed, while this entry
        kept describing the pre-repair state.
        Nothing on this board can be fabricated or assembled until this is
        done. Everything else recorded as "ready" — creepage, symmetry,
        thermals, fiducials, assembly attributes — is necessary and none of it
        is sufficient.
        The 157 count is what the copper pours do NOT already connect. Re-run
        FreeRouting or route by hand, then re-run
        `tools/strip_high_current_tracks.py` every time, so a 3 mm signal-class
        trace never stands in for 50 A copper (12.5.s).
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

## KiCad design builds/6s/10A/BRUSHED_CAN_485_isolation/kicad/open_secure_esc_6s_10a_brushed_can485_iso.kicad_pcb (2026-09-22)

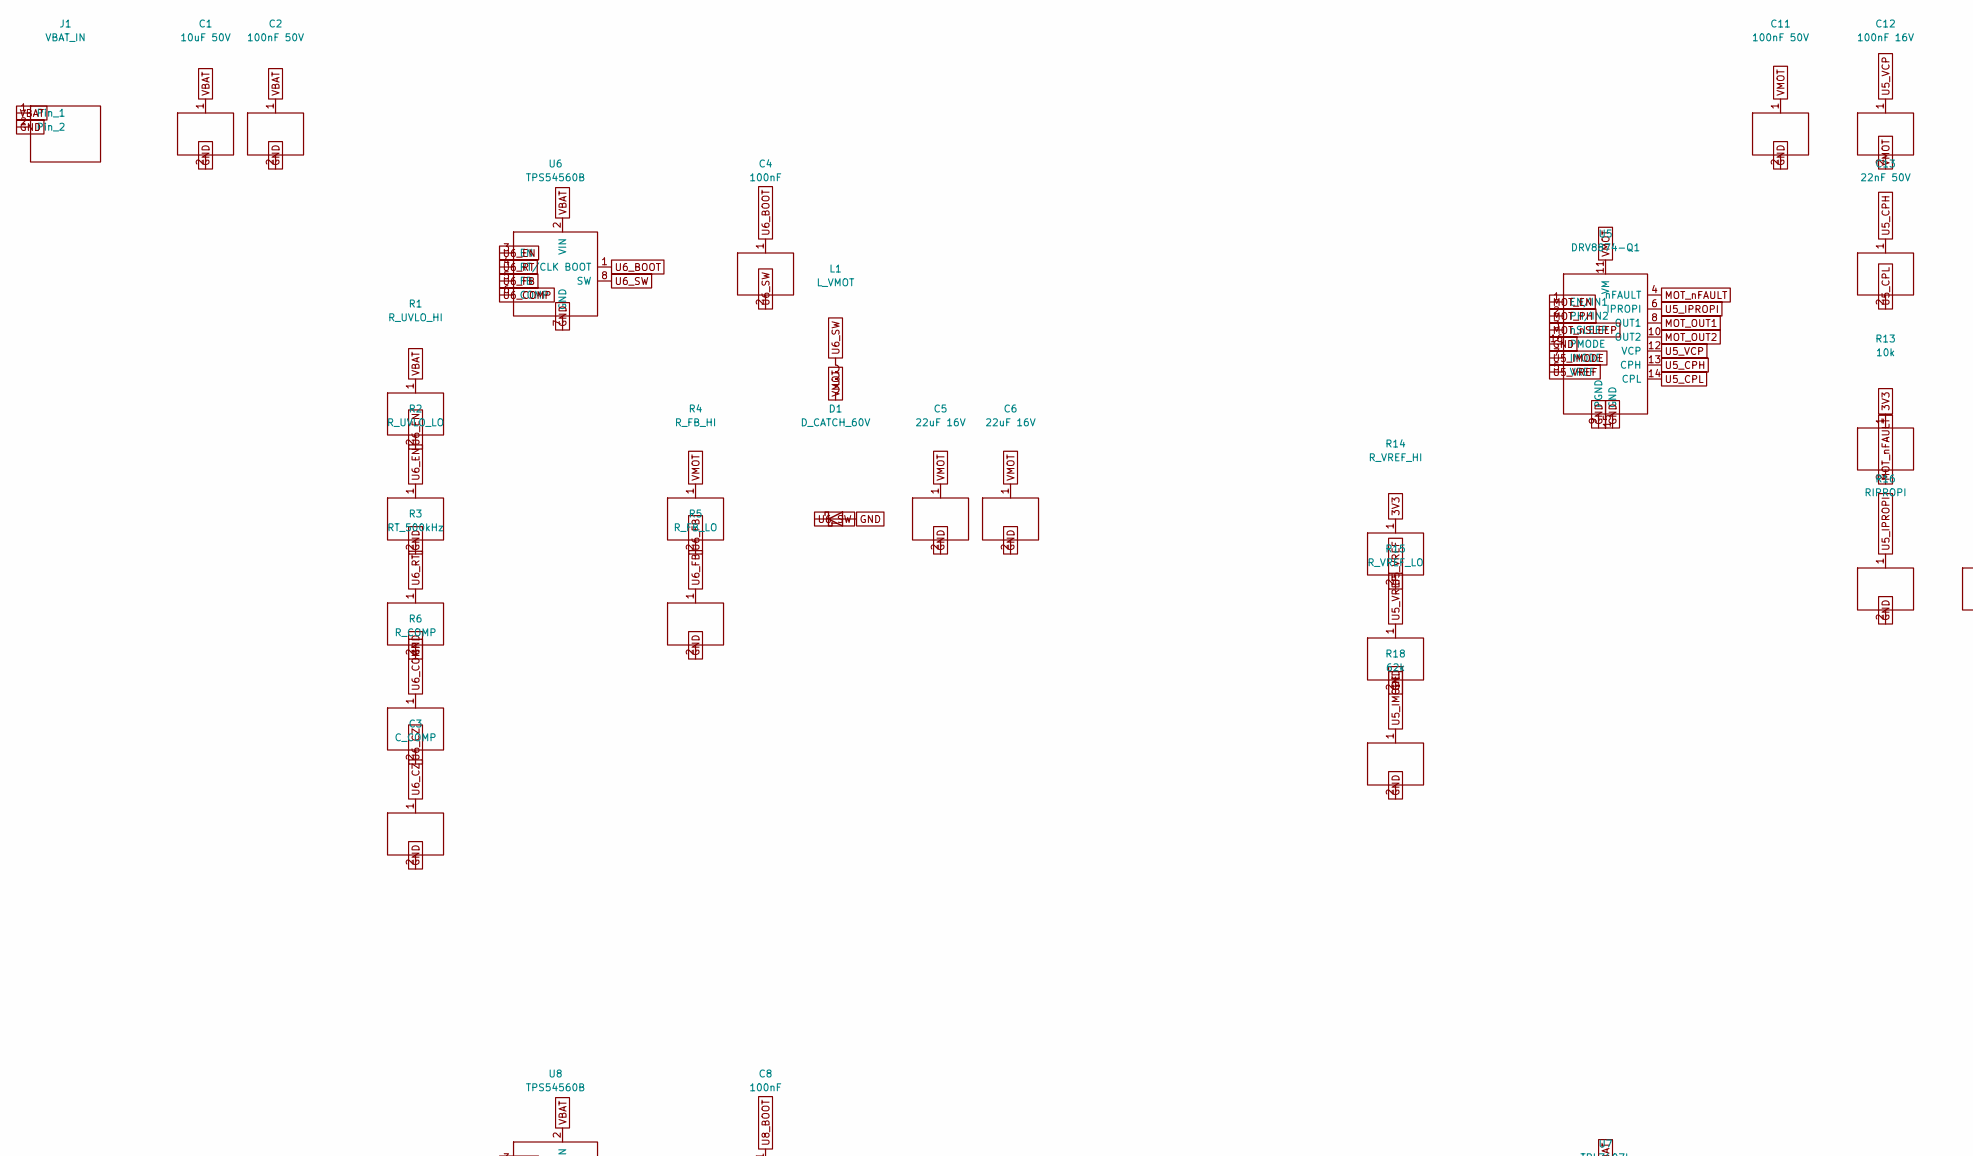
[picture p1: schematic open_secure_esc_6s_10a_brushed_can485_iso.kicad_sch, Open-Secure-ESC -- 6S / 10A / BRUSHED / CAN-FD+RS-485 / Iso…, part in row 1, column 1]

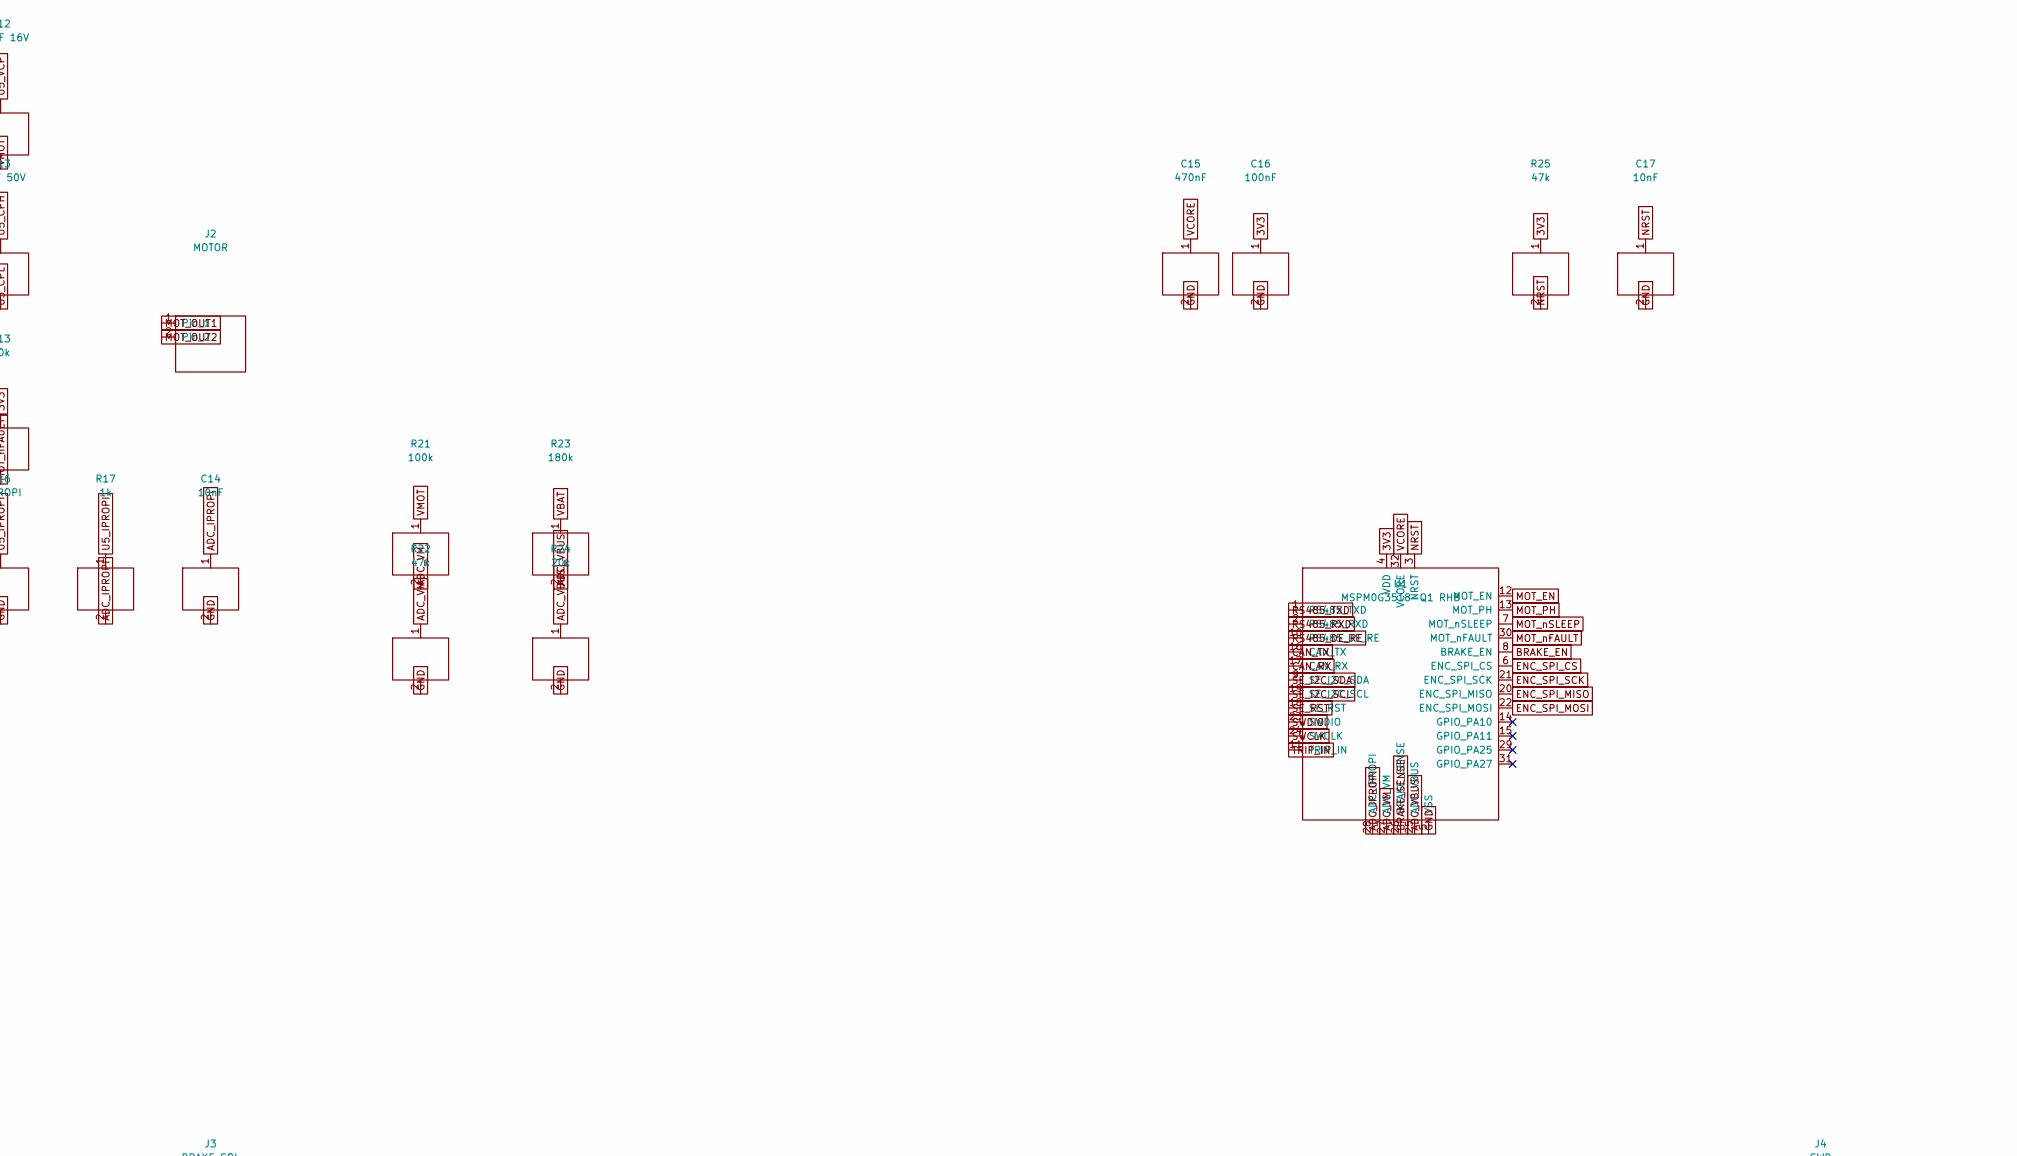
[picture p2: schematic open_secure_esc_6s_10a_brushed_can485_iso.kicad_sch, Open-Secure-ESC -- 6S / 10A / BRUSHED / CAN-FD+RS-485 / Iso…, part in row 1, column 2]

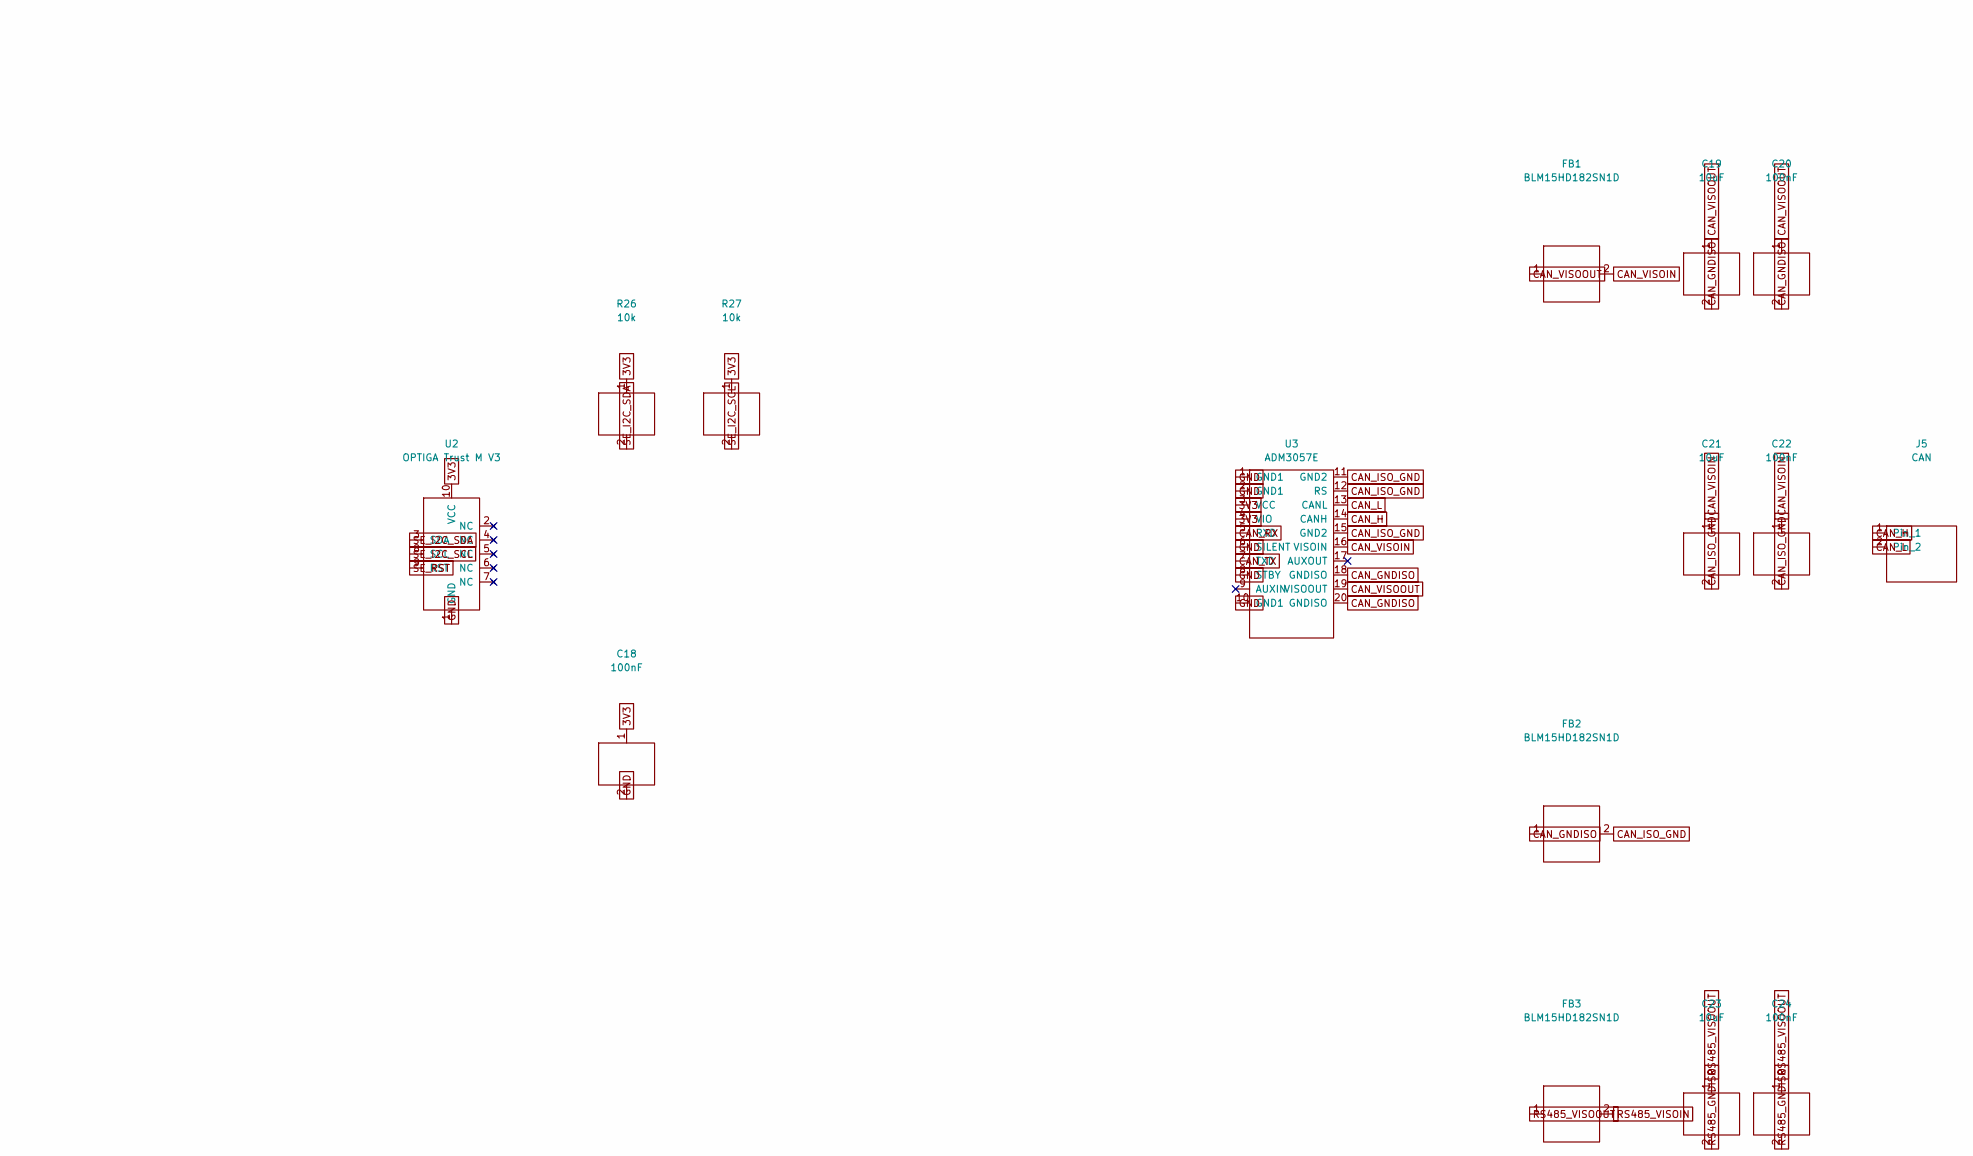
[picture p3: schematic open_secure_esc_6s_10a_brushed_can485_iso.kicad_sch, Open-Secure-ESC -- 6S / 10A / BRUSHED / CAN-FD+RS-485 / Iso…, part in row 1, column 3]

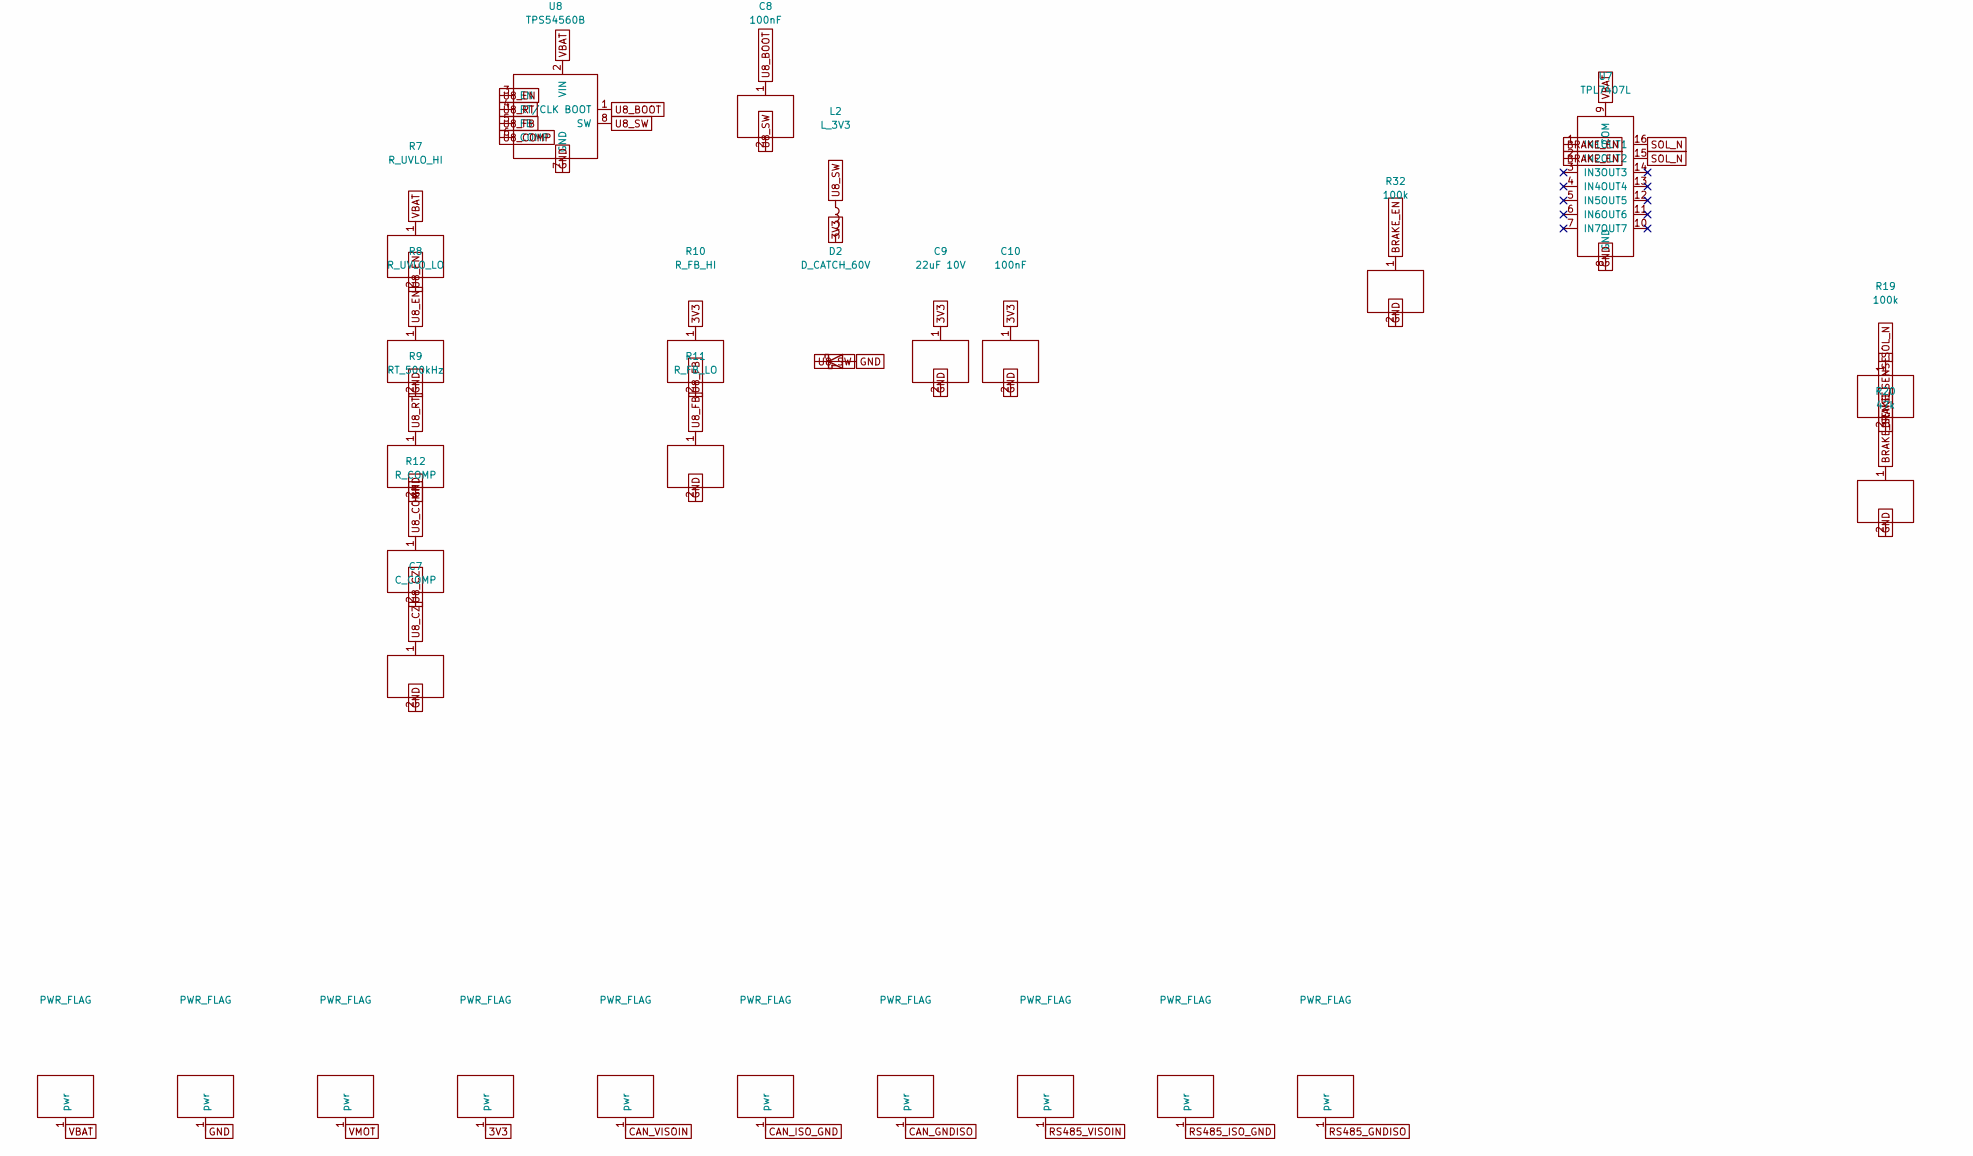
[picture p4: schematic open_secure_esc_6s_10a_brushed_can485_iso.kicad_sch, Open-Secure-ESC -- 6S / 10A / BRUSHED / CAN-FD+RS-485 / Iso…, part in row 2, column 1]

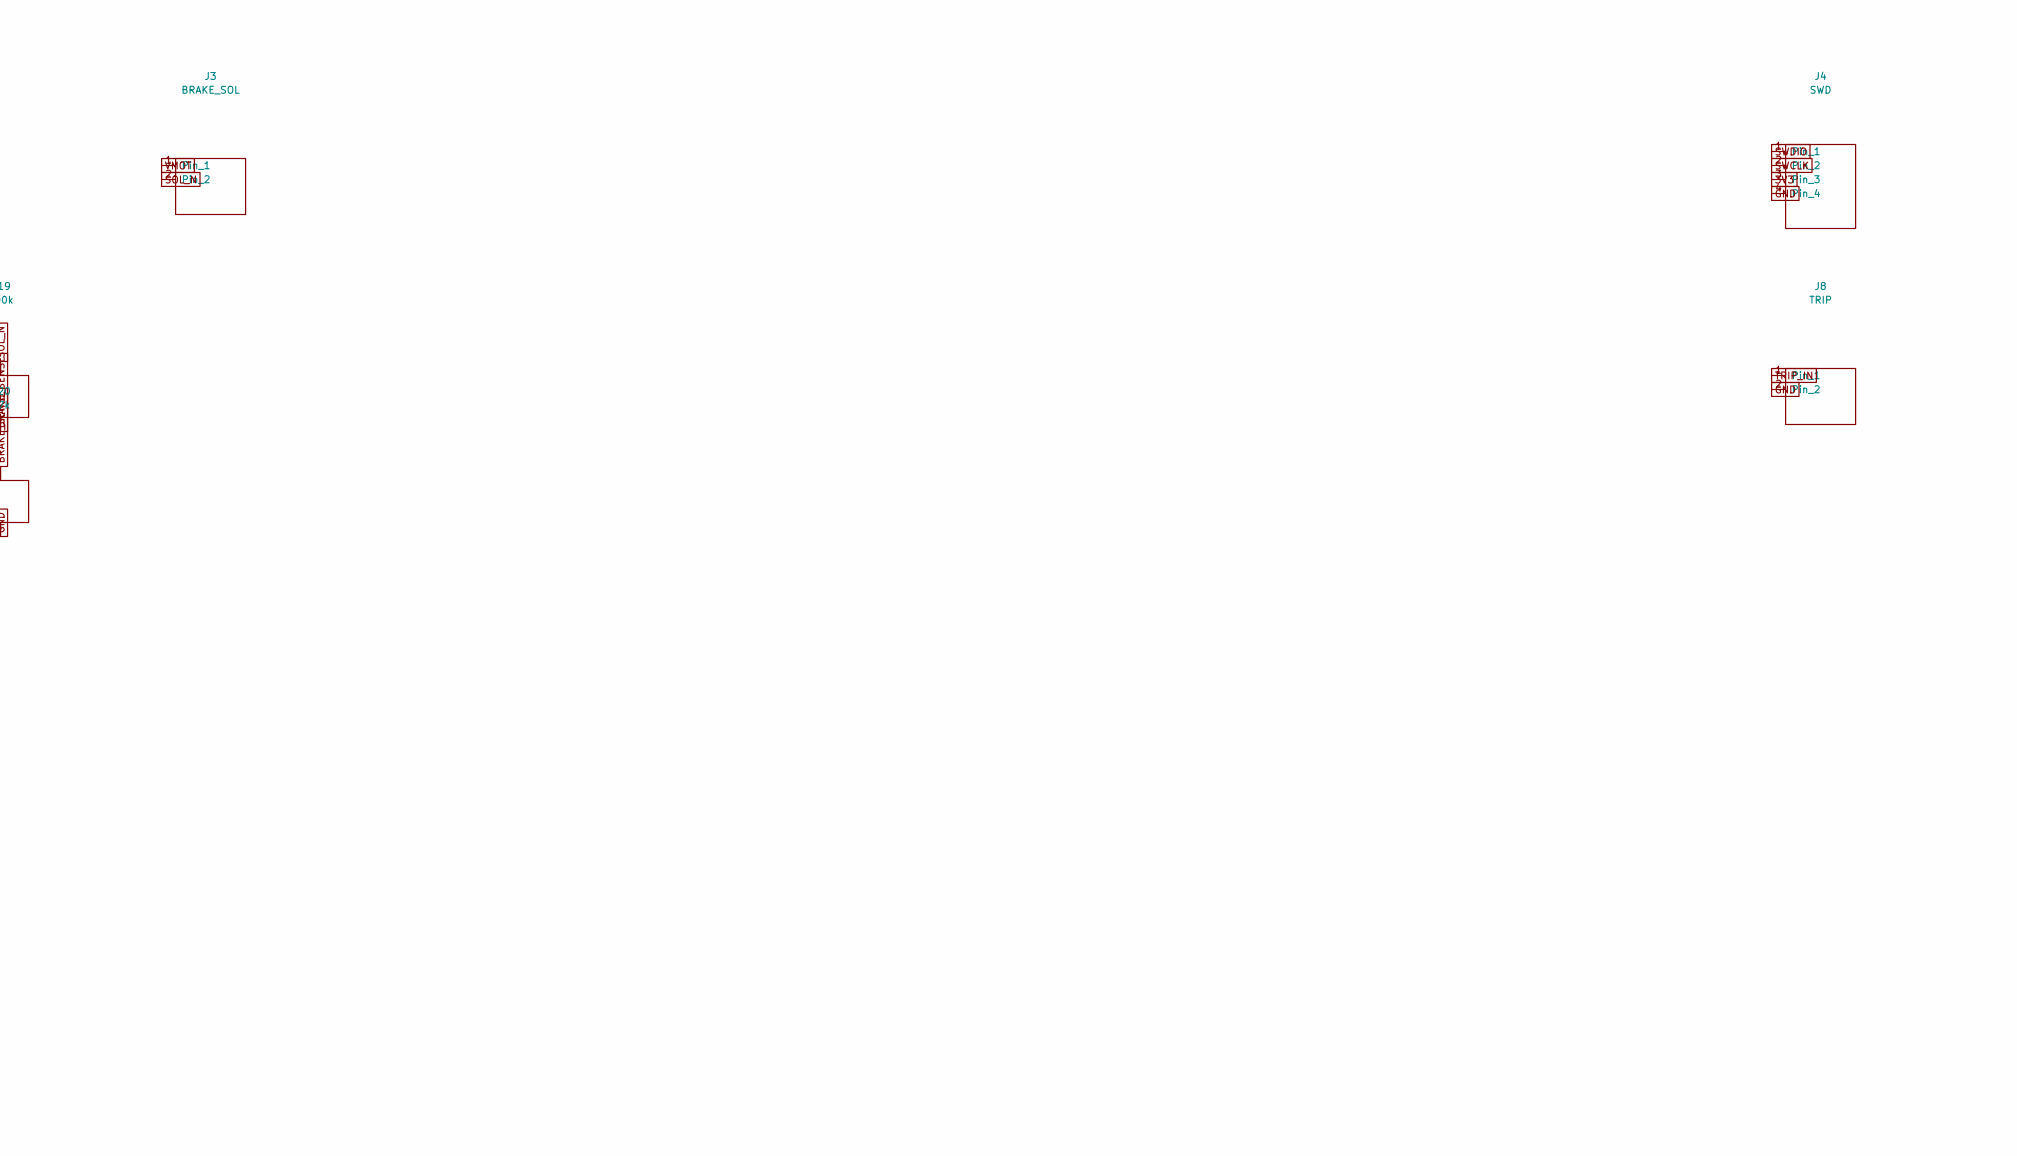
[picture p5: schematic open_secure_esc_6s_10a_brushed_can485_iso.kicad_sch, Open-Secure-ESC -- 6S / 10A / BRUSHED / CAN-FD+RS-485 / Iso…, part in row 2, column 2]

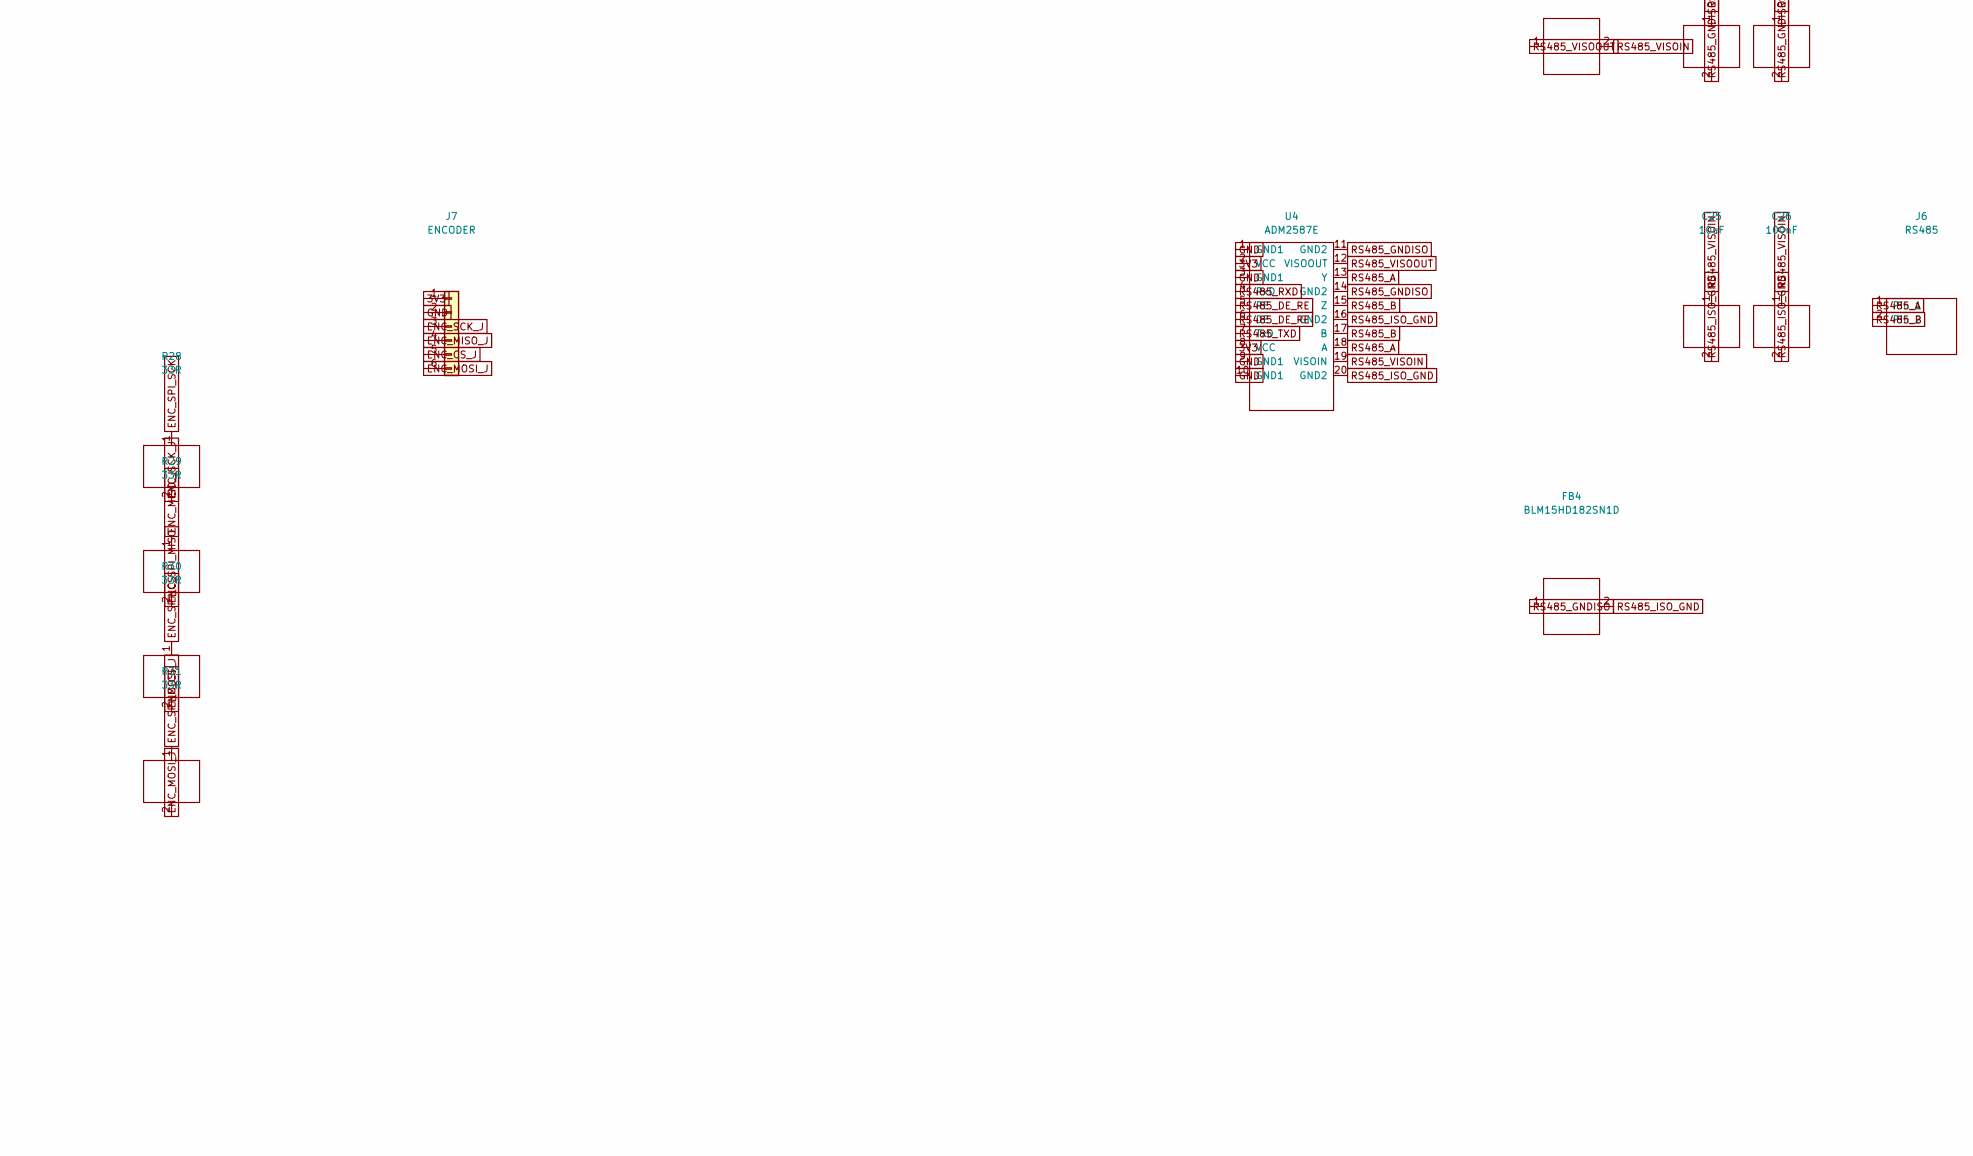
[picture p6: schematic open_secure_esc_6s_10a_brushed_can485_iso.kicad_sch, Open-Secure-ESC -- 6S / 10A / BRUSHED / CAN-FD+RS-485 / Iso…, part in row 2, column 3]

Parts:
C1: 10uF 50V; C_1210_3225Metric
C2, C11: 100nF 50V; C_0603_1608Metric
C3, C7: C_COMP; C_0603_1608Metric
C4, C8, C10, C16, C18, C20, C22, C24, C26: 100nF; C_0603_1608Metric
C5, C6: 22uF 16V; C_1210_3225Metric
C9: 22uF 10V; C_1210_3225Metric
C12: 100nF 16V; C_0603_1608Metric
C13: 22nF 50V; C_0603_1608Metric
C14, C17: 10nF; C_0603_1608Metric
C15: 470nF; C_0603_1608Metric
C19, C21, C23, C25: 10uF; C_0603_1608Metric
D1, D2: D_CATCH_60V; D_SMA
FB1, FB2, FB3, FB4: BLM15HD182SN1D; L_0402_1005Metric
J1: VBAT_IN; JST_XH_B2B-XH-A_1x02_P2.50mm_Vertical
J2: MOTOR; JST_XH_B2B-XH-A_1x02_P2.50mm_Vertical
J3: BRAKE_SOL; JST_XH_B2B-XH-A_1x02_P2.50mm_Vertical
J4: SWD; PinHeader_1x04_P1.27mm_Vertical
J5: CAN; JST_XH_B2B-XH-A_1x02_P2.50mm_Vertical
J6: RS485; JST_XH_B2B-XH-A_1x02_P2.50mm_Vertical
J7: ENCODER; JST_GH_BM06B-GHS-TBT_1x06-1MP_P1.25mm_Vertical
J8: TRIP; PinHeader_1x02_P1.27mm_Vertical
L1: L_VMOT; L_Wuerth_HCI-5040
L2: L_3V3; L_Wuerth_HCI-5040
R1, R7: R_UVLO_HI; R_0603_1608Metric
R2, R8: R_UVLO_LO; R_0603_1608Metric
R3, R9: RT_500kHz; R_0603_1608Metric
R4, R10: R_FB_HI; R_0603_1608Metric
R5, R11: R_FB_LO; R_0603_1608Metric
R6, R12: R_COMP; R_0603_1608Metric
R13, R26, R27: 10k; R_0603_1608Metric
R14: R_VREF_HI; R_0603_1608Metric
R15: R_VREF_LO; R_0603_1608Metric
R16: RIPROPI; R_0603_1608Metric
R17: 1k; R_0603_1608Metric
R18: 62k; R_0603_1608Metric
R19, R21, R32: 100k; R_0603_1608Metric
R20, R22, R25: 47k; R_0603_1608Metric
R23: 180k; R_0603_1608Metric
R24: 20k; R_0603_1608Metric
R28, R29, R30, R31: 33R; R_0603_1608Metric
U1: MSPM0G3518-Q1 RHB; Texas_RHB0032E_VQFN-32-1EP_5x5mm_P0.5mm_EP3.45x3.45mm
U2: OPTIGA Trust M V3; Infineon_PG-USON-10-2-4_3x3mm_P0.5mm_EP1.7x2.5mm
U3: ADM3057E; SOIC-20W_7.5x12.8mm_P1.27mm
U4: ADM2587E; SOIC-20W_7.5x12.8mm_P1.27mm
U5: DRV8874-Q1; TI_PWP0016J_HTSSOP-16_4.4x5mm_P0.65mm_EP2.46x3.55mm
U6, U8: TPS54560B; TI_DDA0008B_HSOIC-8_3.9x4.9mm_P1.27mm_EP2.71x3.4mm
U7: TPL7407L; TSSOP-16_4.4x5mm_P0.65mm

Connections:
3V3: C9.1, C10.1, C16.1, C18.1, J4.3, J7.1, L2.2, R10.1, R13.1, R14.1, R25.1, R26.1, R27.1, U1.4 (VDD), U2.10 (VCC), U3.3 (VCC), U3.4 (VIO), U4.2 (VCC), U4.8 (VCC)
ADC_IPROPI: C14.1, R17.2, U1.28 (ADC_IPROPI)
ADC_VBUS: R23.2, R24.1, U1.25 (ADC_VBUS)
ADC_VM: R21.2, R22.1, U1.27 (ADC_VM)
BRAKE_EN: R32.1, U1.8 (BRAKE_EN), U7.1 (IN1), U7.2 (IN2)
BRAKE_SENSE: R19.2, R20.1, U1.26 (BRAKE_SENSE)
CAN_GNDISO: C19.2, C20.2, FB2.1, U3.18 (GNDISO), U3.20 (GNDISO)
CAN_H: J5.1, U3.14 (CANH)
CAN_ISO_GND: C21.2, C22.2, FB2.2, U3.11 (GND2), U3.12 (RS), U3.15 (GND2)
CAN_L: J5.2, U3.13 (CANL)
CAN_RX: U1.17 (CAN_RX), U3.5 (RXD)
CAN_TX: U1.16 (CAN_TX), U3.7 (TXD)
CAN_VISOIN: C21.1, C22.1, FB1.2, U3.16 (VISOIN)
CAN_VISOOUT: C19.1, C20.1, FB1.1, U3.19 (VISOOUT)
ENC_CS_J: J7.5, R30.2
ENC_MISO_J: J7.4, R29.1
ENC_MOSI_J: J7.6, R31.2
ENC_SCK_J: J7.3, R28.2
ENC_SPI_CS: R30.1, U1.6 (ENC_SPI_CS)
ENC_SPI_MISO: R29.2, U1.20 (ENC_SPI_MISO)
ENC_SPI_MOSI: R31.1, U1.22 (ENC_SPI_MOSI)
ENC_SPI_SCK: R28.1, U1.21 (ENC_SPI_SCK)
GND: C1.2, C2.2, C3.2, C5.2, C6.2, C7.2, C9.2, C10.2, C11.2, C14.2, C15.2, C16.2, C17.2, C18.2, D1.2 (A), D2.2 (A), J1.2, J4.4, J7.2, J8.2, R2.2, R3.2, R5.2, R8.2, R9.2, R11.2, R15.2, R16.2, R18.2, R20.2, R22.2, R24.2, R32.2, U1.5 (VSS), U2.1 (GND), U3.1 (GND1), U3.2 (GND1), U3.6 (SILENT), U3.8 (STBY), U3.10 (GND1), U4.1 (GND1), U4.3 (GND1), U4.9 (GND1), U4.10 (GND1), U5.9 (PGND), U5.15 (GND), U5.16 (PMODE), U6.7 (GND), U7.8 (GND), U8.7 (GND)
MOT_EN: U1.12 (MOT_EN), U5.1 (EN/IN1)
MOT_OUT1: J2.1, U5.8 (OUT1)
MOT_OUT2: J2.2, U5.10 (OUT2)
MOT_PH: U1.13 (MOT_PH), U5.2 (PH/IN2)
MOT_nFAULT: R13.2, U1.30 (MOT_nFAULT), U5.4 (nFAULT)
MOT_nSLEEP: U1.7 (MOT_nSLEEP), U5.3 (nSLEEP)
NRST: C17.1, R25.2, U1.3 (NRST)
RS485_A: J6.1, U4.13 (Y), U4.18 (A)
RS485_B: J6.2, U4.15 (Z), U4.17 (B)
RS485_DE_RE: U1.10 (RS485_DE_RE), U4.5 (RE), U4.6 (DE)
RS485_GNDISO: C23.2, C24.2, FB4.1, U4.11 (GND2), U4.14 (GND2)
RS485_ISO_GND: C25.2, C26.2, FB4.2, U4.16 (GND2), U4.20 (GND2)
RS485_RXD: U1.2 (RS485_RXD), U4.4 (RxD)
RS485_TXD: U1.1 (RS485_TXD), U4.7 (TxD)
RS485_VISOIN: C25.1, C26.1, FB3.2, U4.19 (VISOIN)
RS485_VISOOUT: C23.1, C24.1, FB3.1, U4.12 (VISOOUT)
SE_I2C_SCL: R27.2, U1.19 (SE_I2C_SCL), U2.8 (SCL)
SE_I2C_SDA: R26.2, U1.9 (SE_I2C_SDA), U2.3 (SDA)
SE_RST: U1.18 (SE_RST), U2.9 (RST)
SOL_N: J3.2, R19.1, U7.15 (OUT2), U7.16 (OUT1)
SWCLK: J4.2, U1.24 (SWCLK)
SWDIO: J4.1, U1.23 (SWDIO)
TRIP_IN: J8.1, U1.11 (TRIP_IN)
U5_CPH: C13.1, U5.13 (CPH)
U5_CPL: C13.2, U5.14 (CPL)
U5_IMODE: R18.1, U5.7 (IMODE)
U5_IPROPI: R16.1, R17.1, U5.6 (IPROPI)
U5_VCP: C12.1, U5.12 (VCP)
U5_VREF: R14.2, R15.1, U5.5 (VREF)
U6_BOOT: C4.1, U6.1 (BOOT)
U6_COMP: R6.1, U6.6 (COMP)
U6_CZ: C3.1, R6.2
U6_EN: R1.2, R2.1, U6.3 (EN)
U6_FB: R4.2, R5.1, U6.5 (FB)
U6_RT: R3.1, U6.4 (RT/CLK)
U6_SW: C4.2, D1.1 (K), L1.1, U6.8 (SW)
U8_BOOT: C8.1, U8.1 (BOOT)
U8_COMP: R12.1, U8.6 (COMP)
U8_CZ: C7.1, R12.2
U8_EN: R7.2, R8.1, U8.3 (EN)
U8_FB: R10.2, R11.1, U8.5 (FB)
U8_RT: R9.1, U8.4 (RT/CLK)
U8_SW: C8.2, D2.1 (K), L2.1, U8.8 (SW)
VBAT: C1.1, C2.1, J1.1, R1.1, R7.1, R23.1, U6.2 (VIN), U7.9 (COM), U8.2 (VIN)
VCORE: C15.1, U1.32 (VCORE)
VMOT: C5.1, C6.1, C11.1, C12.2, J3.1, L1.2, R4.1, R21.1, U5.11 (VM)

Board: 2 copper layers, 82 parts (0 on the bottom side), 69 nets, no tracks yet.

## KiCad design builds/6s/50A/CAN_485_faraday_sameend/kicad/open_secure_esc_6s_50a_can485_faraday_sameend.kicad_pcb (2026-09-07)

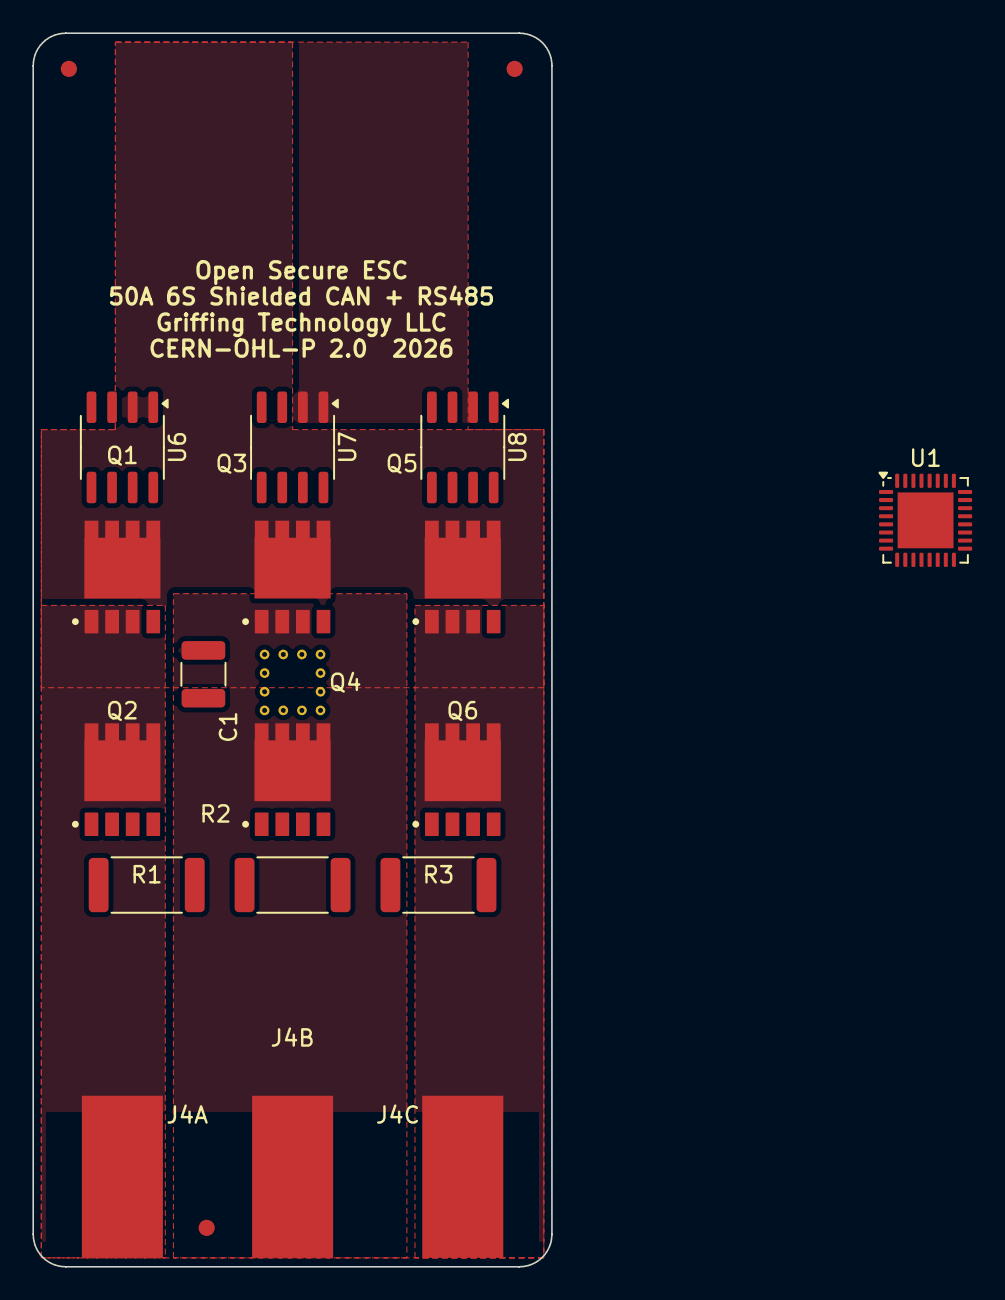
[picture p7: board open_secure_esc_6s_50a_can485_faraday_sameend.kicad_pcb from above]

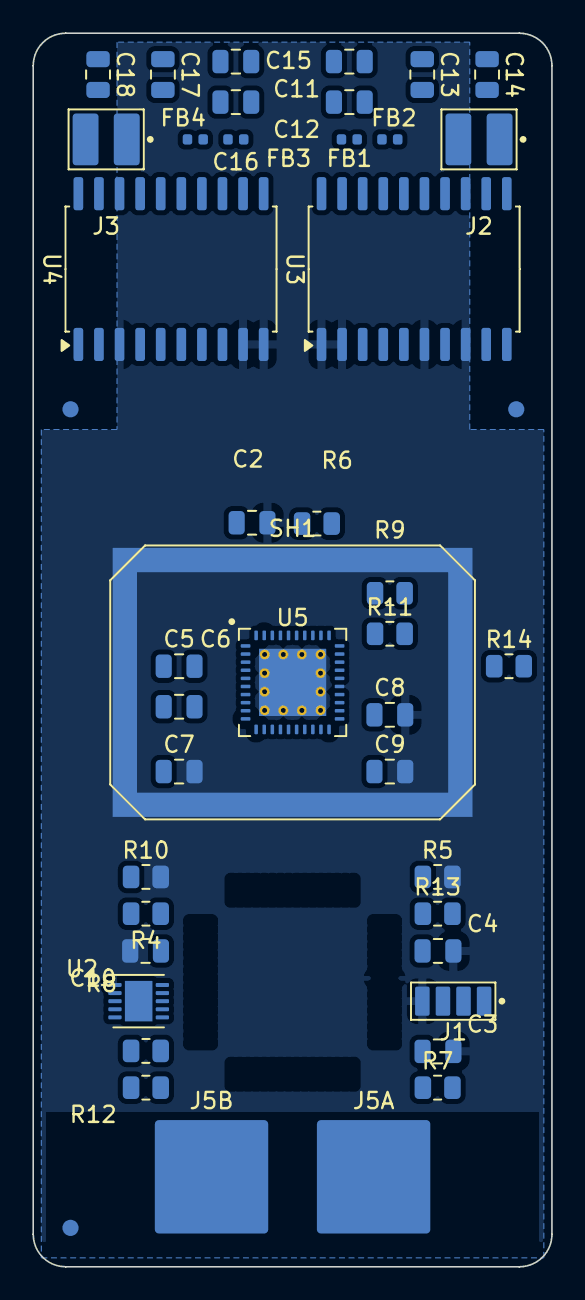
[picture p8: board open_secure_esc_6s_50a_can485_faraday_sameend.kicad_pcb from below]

Board: 4 copper layers, 32.0 x 76.1 mm, 65 parts (45 on the bottom side), 62 nets, no tracks yet.

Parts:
C1: C_1210_3225Metric
C2, C3, C4, C5, C6, C7, C8, C9, C10: C_0805_2012Metric
C11, C15: 10uF; C_0805_2012Metric
C12: 220nF; C_0805_2012Metric
C13, C16, C17: 100nF; C_0805_2012Metric
C14, C18: 10nF; C_0805_2012Metric
FB1, FB2, FB3, FB4: BLM15HD182SN1D; L_0402_1005Metric
FID1, FID2, FID3, FID4, FID5, FID6: Fiducial_1mm_Mask2mm
J1: SolderPad_1x04_SMD_P1.27mm_Probe
J2, J3: SolderPad_1x02_SMD_P2.54mm
J4A, J4B, J4C: SolderWirePad_1x01_SMD_5x10mm
J5A, J5B: SolderWire-6sqmm_1x01_D3.5mm_OD7mm
Q1, Q2, Q3, Q4, Q5, Q6: Toshiba_2-5W1A_SOP-Advance-N_5.15x6.1mm_P1.27mm
R1, R2, R3: R_2512_6332Metric
R4, R5, R6, R7, R8, R9, R10, R11, R12, R13, R14: R_0805_2012Metric
SH1: Wurth_WE-SHC_3670209_Frame_15.3x20.9mm
U1: MSPM0G3518_Q1_RHB; Texas_RHB0032E_VQFN-32-1EP_5x5mm_P0.5mm_EP3.45x3.45mm
U2: Infineon_PG-USON-10-2-4_3x3mm_P0.5mm_EP1.7x2.5mm
U3, U4: SOIC-20W_7.5x12.8mm_P1.27mm
U5: TI_RTA0040B_WQFN-40_6x6mm_P0.5mm_EP4.15x4.15mm
U6, U7, U8: SOIC-8_3.9x4.9mm_P1.27mm

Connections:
3V3: C2.1, C4.1, C10.1, J1.3, R4.1, R6.1, R7.1, R9.1, R11.1, R12.1, R13.1, R14.1, U1.4, U2.10, U3.3, U3.4, U4.2, U4.8, U6.6, U7.6, U8.6
ADC_IU: U1.28, U6.5
ADC_IV: U1.27, U7.5
ADC_IW: U1.29, U8.5
CAN_GNDISO: C11.2, C12.2, FB2.1, U3.18, U3.20
CAN_ISO_GND: C13.2, C14.2, FB2.2, U3.11, U3.12, U3.15
CAN_VISOIN: C13.1, C14.1, FB1.2, U3.16
CAN_VISOOUT: C11.1, C12.1, FB1.1, U3.19
GD_SPI_MISO: R14.2, U1.20, U5.27
GND: C1.2, C2.2, C3.2, C4.2, C7.2, C8.2, C9.2, C10.2, J1.4, J5B.1, R1.2, R2.2, R3.2, R5.2, R10.2, SH1.1, U1.5, U2.1, U3.1, U3.2, U3.6, U3.8, U3.10, U4.1, U4.3, U4.9, U4.10, U5.10, U5.11, U5.20, U5.25, U5.39, U5.41, U6.1, U6.2, U7.1, U7.2, U8.1, U8.2
ISENSE_A_HI: Q2.1, Q2.2, Q2.3, R1.1, U5.9, U6.8
ISENSE_B_HI: Q4.1, Q4.2, Q4.3, R2.1, U5.12, U7.8
ISENSE_C_HI: Q6.1, Q6.2, Q6.3, R3.1, U5.19, U8.8
NRST: R6.2, R7.2, U1.3
unnamed: J1.1, U1.23
unnamed: J1.2, U1.24
unnamed: J2.1, U3.14
unnamed: J2.2, U3.13
unnamed: Q1.4, U5.6
unnamed: Q2.4, U5.8
unnamed: Q3.4, U5.15
unnamed: Q4.4, U5.13
unnamed: Q5.4, U5.16
unnamed: Q6.4, U5.18
unnamed: U1.17, U3.5
unnamed: U1.16, U3.7
unnamed: U1.6, U5.30
unnamed: U1.22, U5.28
unnamed: U1.21, U5.29
unnamed: U1.12, U5.32
unnamed: U1.13, U5.33
unnamed: U1.7, U5.34
unnamed: U1.8, U5.35
unnamed: U1.14, U5.36
unnamed: U1.15, U5.37
unnamed: U1.2, U4.4
unnamed: U1.1, U4.7
unnamed: C5.1, U5.2
unnamed: C5.2, U5.1
unnamed: C8.1, U5.38
unnamed: R9.2, U5.31
unnamed: C6.1, U5.5
unnamed: C9.1, U5.40
unnamed: C7.1, U5.24
unnamed: R11.2, U5.26
PH_A: J4A.1, Q1.1, Q1.2, Q1.3, Q2.5, Q2.6, Q2.7, Q2.8, U5.7
PH_B: J4B.1, Q3.1, Q3.2, Q3.3, Q4.5, Q4.6, Q4.7, Q4.8, U5.14
PH_C: J4C.1, Q5.1, Q5.2, Q5.3, Q6.5, Q6.6, Q6.7, Q6.8, U5.17
RS485_A: J3.1, U4.13, U4.18
RS485_B: J3.2, U4.15, U4.17
RS485_DE_RE: U1.10, U4.5, U4.6
RS485_GNDISO: C15.2, C16.2, FB4.1, U4.11, U4.14
RS485_ISO_GND: C17.2, C18.2, FB4.2, U4.16, U4.20
RS485_VISOIN: C17.1, C18.1, FB3.2, U4.19
RS485_VISOOUT: C15.1, C16.1, FB3.1, U4.12
SE_I2C_SCL: R13.2, U1.19, U2.8
SE_I2C_SDA: R12.2, U1.9, U2.3
SE_RST: U1.18, U2.9
VBUS_SENSE: R8.2, R10.1, U1.25
VCORE: C3.1, U1.32
VM: C1.1, C6.2, J5A.1, Q1.5, Q1.6, Q1.7, Q1.8, Q3.5, Q3.6, Q3.7, Q3.8, Q5.5, Q5.6, Q5.7, Q5.8, R8.1, U5.3, U5.4
VREF_MID: R4.2, R5.1, U6.3, U6.7, U7.3, U7.7, U8.3, U8.7

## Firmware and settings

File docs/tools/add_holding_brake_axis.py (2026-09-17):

#!/usr/bin/env python3
"""Add the Holding Brake axis and the tilt-build rows to docs/decision-matrix.xlsx.

Governed by AGENTS.md. Companion to the Serenity-UAV plan
``docs/plans/2026-09-17-001-feat-tilt-controller-open-secure-esc-build-plan.md``
(U2) and to ``builds/6s/10A/BRUSHED_CAN_485_isolation/README.md``.

WHY THIS AXIS EXISTS
--------------------
The Serenity nacelle-tilt actuator is a brushed gearmotor driving a
multi-start worm that is NOT self-locking (Serenity
``docs/solutions/design-patterns/self-locking-worm-and-vectoring-bandwidth-
are-mutually-exclusive.md``). The only unpowered hold is a spring-applied,
power-released pin brake, and the controller must drive its solenoid so
that:

  * de-energised = engaged (the brake holds when the controller's own
    power path fails);
  * an MCU reset or a floating GPIO also engages it (the driver input needs
    a pull-down, not just firmware);
  * the coil's inductive kick is clamped;
  * brake state is readable on the bus.

None of the existing axes can express that. A brake output is a safety
property of the build, so it is carried as its own axis with a Fail-state
column rather than as a build-local note.

WHAT THIS SCRIPT CHANGES
------------------------
1. Adds (or replaces) a **Holding Brake** sheet with two rows:
   ``None`` and ``Low-side solenoid driver, spring-applied``.
2. Resolves the **Motor** sheet's ``Brushed (DC)`` row: the gate-driver
   cell was ``TBD`` since 2026-08-16 (TODO.md 12.6.a). It now names the
   TI DRV8874-Q1 integrated H-bridge [63] (non-Q1 twin [62]), and the
   shunt count drops to 0 because the driver's IPROPI current mirror
   replaces the shunt + INA240 of the brushless tiers.
3. Appends a **Magnetic absolute (SPI/SSI)** row to the **Shaft Sensor**
   sheet for the Broadcom AEAT-8800-Q24 [64], read remotely over a keyed
   header.
4. Adds an override note to the **Amperage** sheet: for a brushed build the
   Motor sheet's bridge row overrides the FET / gate-driver / shunt /
   current-sense-amp columns; the Amperage sheet still governs copper and
   connector class. The 10 A row's tag cell gains [62], [63].
5. Lists the new sheet in the **Legend**.

Every part named here has a local, verified datasheet (REFERENCES.md
[62]-[66]). Cells that have no verified answer keep the literal TBD marker.

The script is idempotent: re-running replaces the Holding Brake sheet,
rewrites the same Motor/Amperage cells to the same values, and does not
append a second Shaft Sensor row or Legend line. The workbook is backed up
to a timestamped file first so the existing ``decision-matrix.xlsx.bak`` is
not clobbered.

Requires: openpyxl

Usage:
    python3 docs/tools/add_holding_brake_axis.py [--dry-run]

Then regenerate the JSON export:
    python3 docs/tools/decision_matrix_to_json.py
"""
# Authored by Claude Opus 5 (Anthropic) 2026-09-17 under the direction of
# Steve Griffing, PE(CSE), CISSP-ISSEP, CPP. AI-generated; every part
# selection is carried from REFERENCES.md [62]-[66] or explicitly left open.
# Not yet human-reviewed.

import argparse
import shutil
from datetime import datetime, timezone
from pathlib import Path

import openpyxl
from openpyxl.styles import Alignment, Font, PatternFill

REPO = Path(__file__).resolve().parents[2]
WORKBOOK = REPO / "docs" / "decision-matrix.xlsx"

HEADER_FILL = PatternFill("solid", fgColor="FF2F5597")
HEADER_FONT = Font(bold=True, size=10, color="FFFFFFFF")
TITLE_FONT = Font(bold=True, size=16)
SUB_FONT = Font(size=10)
BODY_ALIGN = Alignment(wrap_text=True, vertical="top")
HEADER_ALIGN = Alignment(wrap_text=True, vertical="center")

# --------------------------------------------------------- Holding Brake -----
BRAKE = {
    "title": "Holding Brake Decision Matrix",
    "subtitle": (
        "Build axis: Holding Brake (None / Low-side solenoid driver, spring-applied)"
    ),
    "widths": [28, 34, 40, 26, 40, 30, 44, 18, 22],
    "columns": [
        "Brake Option",
        "Actuation",
        "Fail-state",
        "MCU Pins Required",
        "Additional BOM Component",
        "Connector",
        "Firmware Workflow Steps",
        "REFERENCES.md Tags",
        "Status",
    ],
    "rows": [
        [
            "None",
            (
                "No holding brake. The load is held by the motor's own "
                "drag, a self-locking transmission, or nothing."
            ),
            (
                "Not applicable -- the build has no brake to fail. A "
                "non-self-locking transmission on a load that must hold "
                "unpowered may NOT select this row."
            ),
            "0",
            "None",
            "None",
            "None",
            "-",
            "No part needed",
        ],
        [
            "Low-side solenoid driver, spring-applied",
            (
                "Spring-applied, power-released pin brake. A pull "
                "solenoid retracts the pin while its coil is energised; "
                "the spring engages the pin when the coil is released. "
                "The coil is switched on its low side."
            ),
            (
                "De-energised = engaged. The driver input carries a "
                "pull-down so an MCU reset, brown-out or floating GPIO "
                "engages the brake without firmware; the coil's inductive "
                "kick is clamped; brake state (drive-pin readback) is "
                "published on the bus. Engage-on-fault: the motor driver's "
                "nFAULT is a brake-engage input for firmware."
            ),
            (
                "1 digital out (BRAKE_EN) plus 1 digital in or ADC for "
                "state readback; optionally 1 ADC for the coil supply "
                "rail so the pin is never dropped into a driven "
                "castellation."
            ),
            (
                "TI TPL7407L [66]: 40 V 7-channel NMOS low-side array, "
                "600 mA per channel (channels paralleled for the load), "
                "1 MOhm input pull-down per channel, internal clamp "
                "diodes to COM. Return COM to the pack-side rail so the "
                "clamp sits above the coil supply and inside the COM "
                "range (8.5-40 V, [66] Sec.6.3). The solenoid itself is a "
                "host-side part outside this axis (Serenity-UAV item "
                "BRK-4); this row carries only the driver."
            ),
            "2-pin (COIL+, COIL-) keyed header; polarity marked",
            (
                "Release only on an authenticated release command after "
                "the loop has unloaded the pin; sequence release -> move "
                "-> settle (encoder stationary) -> engage; engage on "
                "nFAULT, on bus loss after a timeout, and on coil-rail "
                "droop below the solenoid hold-in voltage; publish brake "
                "state every telemetry frame."
            ),
            "[66]",
            "Verified (local PDF)",
        ],
    ],
}

BRAKE_NOTES = (
    "A brake on the actuator shaft protects against loss of drive, not "
    "against a broken transmission downstream of it. The 'Fail-state' "
    "column is the safety property this axis exists to record -- a build "
    "that selects the solenoid row must reproduce every item in it, not "
    "just the part number. First instance: "
    "builds/6s/10A/BRUSHED_CAN_485_isolation/ (Serenity-UAV nacelle tilt)."
)

# ------------------------------------------------------- Shaft Sensor row ---
MAGNETIC_ROW = [
    "Magnetic absolute (SPI/SSI)",
    (
        "Single-turn absolute angle from an on-axis Hall sensor IC reading "
        "a diametric two-pole magnet on the shaft end; 10- to 16-bit "
        "absolute word over SSI/SPI, optional ABI/UVW/PWM outputs. Multi-"
        "turn position is accumulated in firmware."
    ),
    (
        "3 (SCLK, DO, NSL/CS) for SSI, 4 with DI for SPI; sensor supply "
        "3.3 V. The sensor may sit off-board on a short cable."
    ),
    (
        "Broadcom AEAT-8800-Q24 [64], QFN-24 5 x 5 mm, 3.3 V or 5 V "
        "operation, SSI 3-wire absolute output. Series resistors and ESD "
        "protection on each line per docs/design-speed-sensor-integration.md."
    ),
    "6-pin keyed (3V3, GND, SCLK, DO, NSL, DI) with shield/drain optional",
    (
        "Read the absolute word each control tick; unwrap turns across the "
        "0/full-scale boundary; home the multi-turn count from an outer "
        "absolute reference (a host sensor over the bus) at power-up; "
        "declare 'stationary' from this sensor, not from motor current."
    ),
    "[64]",
    "Verified (local PDF)",
]

# ------------------------------------------------------------ Motor row ------
MOTOR_UPDATES = {
    "Gate Driver Part": (
        "TI DRV8874-Q1 [63] integrated N-channel H-bridge (non-Q1 twin "
        "DRV8874 [62]): 4.5-37 V VM, 6 A peak, 100 mOhm typ per FET, "
        "PH/EN or PWM control, IPROPI current mirror 450 uA/A, VREF/ITRIP "
        "current regulation, UVLO/CPUV/OCP/TSD. Tier 1 (2S-6S, 10-20 A) "
        "per docs/OpenSecureESC-Brushed-Specifications.md Sec.1; every "
        "fault coasts the bridge ([63] Table 7)."
    ),
    "Shunt Qty": (
        "0 -- the driver's IPROPI current mirror replaces the shunt and "
        "current-sense amplifier of the brushless tiers ([63] Sec.7.3.3.1)"
    ),
    "REFERENCES.md Tags": "[62], [63]",
    "Status": "Verified (local PDF)",
}

AMPERAGE_NOTE = (
    " -- BRUSHED BUILDS (2026-09-17): the FET Part, Gate Driver Part, Shunt "
    "and Current-Sense Amp columns of this sheet are brushless-shaped and "
    "are OVERRIDDEN by the Motor sheet's bridge row for a Brushed (DC) "
    "build (Tier 1: DRV8874-Q1 [63] integrated bridge, no shunt). This "
    "sheet still governs the copper and connector class for the tier."
)


def write_sheet(wb, name: str, spec: dict, notes: str) -> None:
    """Create (or replace) one axis sheet in the shipped house style."""
    if name in wb.sheetnames:
        del wb[name]
    ws = wb.create_sheet(name)

    ws["A1"] = spec["title"]
    ws["A1"].font = TITLE_FONT
    ws["A1"].alignment = Alignment(vertical="center")
    ws["A2"] = spec["subtitle"]
    ws["A2"].font = SUB_FONT

    for col, header in enumerate(spec["columns"], start=1):
        c = ws.cell(row=4, column=col, value=header)
        c.fill, c.font, c.alignment = HEADER_FILL, HEADER_FONT, HEADER_ALIGN

    for r, row in enumerate(spec["rows"], start=5):
        for col, value in enumerate(row, start=1):
            c = ws.cell(row=r, column=col, value=value)
            c.alignment = BODY_ALIGN

    note_row = 5 + len(spec["rows"]) + 1
    nc = ws.cell(row=note_row, column=1, value="Note: " + notes)
    nc.alignment = BODY_ALIGN
    nc.font = SUB_FONT

    for col, width in enumerate(spec["widths"], start=1):
        ws.column_dimensions[ws.cell(row=4, column=col).column_letter].width = width
    ws.freeze_panes = "A5"


def header_index(ws, header_row: int = 4) -> dict:
    """Map column header text -> 1-based column number."""
    return {
        str(ws.cell(row=header_row, column=c).value).strip(): c
        for c in range(1, ws.max_column + 1)
        if ws.cell(row=header_row, column=c).value is not None
    }


def find_row(ws, key_col: int, key: str, header_row: int = 4) -> int | None:
    """Return the row whose key column equals ``key`` (data rows only)."""
    for r in range(header_row + 1, ws.max_row + 1):
        if str(ws.cell(row=r, column=key_col).value or "").strip() == key:
            return r
    return None


def resolve_motor_row(wb) -> None:
    """Fill the Brushed (DC) row's open cells from REFERENCES.md [62]/[63]."""
    ws = wb["Motor"]
    cols = header_index(ws)
    r = find_row(ws, cols["Motor Type"], "Brushed (DC)")
    if r is None:
        raise SystemExit("Motor sheet: 'Brushed (DC)' row not found")
    for header, value in MOTOR_UPDATES.items():
        c = ws.cell(row=r, column=cols[header], value=value)
        c.alignment = BODY_ALIGN


def add_magnetic_sensor_row(wb) -> None:
    """Append the magnetic-absolute row unless it is already present."""
    ws = wb["Shaft Sensor"]
    cols = header_index(ws)
    if find_row(ws, cols["Sensor Type"], MAGNETIC_ROW[0]) is not None:
        return
    # Data rows run contiguously from row 5; append after the last one.
    r = 5
    while ws.cell(row=r, column=cols["Sensor Type"]).value not in (None, ""):
        r += 1
    for col, value in enumerate(MAGNETIC_ROW, start=1):
        c = ws.cell(row=r, column=col, value=value)
        c.alignment = BODY_ALIGN


def annotate_amperage(wb) -> None:
    """Record the brushed override on the notes cell and tag the 10 A row."""
    ws = wb["Amperage"]
    cols = header_index(ws)
    r10 = find_row(ws, cols["Tier (A)"], "10")
    if r10 is None:
        raise SystemExit("Amperage sheet: 10 A row not found")
    tags = str(ws.cell(row=r10, column=cols["REFERENCES.md Tags"]).value or "")
    for tag in ("[62]", "[63]"):
        if tag not in tags:
            tags = f"{tags}, {tag}" if tags else tag
    ws.cell(row=r10, column=cols["REFERENCES.md Tags"], value=tags)

    # The notes cell is the first non-empty column-A cell after the data.
    r = r10
    while ws.cell(row=r, column=1).value not in (None, ""):
        r += 1
    while ws.cell(row=r, column=1).value in (None, "") and r < ws.max_row + 2:
        r += 1
    note = str(ws.cell(row=r, column=1).value or "")
    if "BRUSHED BUILDS" not in note:
        ws.cell(row=r, column=1, value=note + AMPERAGE_NOTE).alignment = BODY_ALIGN


def update_legend(wb) -> None:
    """Add the Holding Brake sheet to the Legend's sheet list."""
    ws = wb["Legend"]
    existing = {
        str(ws.cell(row=r, column=1).value or "").strip()
        for r in range(1, ws.max_row + 1)
    }
    if "Holding Brake" in existing:
        return
    row = ws.max_row + 1
    ws.cell(row=row, column=1, value="Holding Brake").font = Font(size=10)
    ws.cell(
        row=row,
        column=2,
        value=(
            "None / low-side solenoid driver: actuation, fail-state (the "
            "safety property), MCU pins, driver part, connector, firmware "
            "sequencing."
        ),
    ).alignment = BODY_ALIGN
    ws.cell(
        row=row + 2,
        column=1,
        value=(
            f"Amended {datetime.now(timezone.utc).date().isoformat()}: added "
            "the Holding Brake axis; resolved the Motor sheet's Brushed (DC) "
            "row (DRV8874-Q1 [63]); added the magnetic-absolute shaft-sensor "
            "row (AEAT-8800-Q24 [64])."
        ),
    ).font = Font(size=10, italic=True)


def main() -> int:
    """Apply every change to the workbook."""
    ap = argparse.ArgumentParser(description=__doc__)
    ap.add_argument("--dry-run", action="store_true")
    args = ap.parse_args()

    wb = openpyxl.load_workbook(WORKBOOK)
    before = list(wb.sheetnames)

    write_sheet(wb, "Holding Brake", BRAKE, BRAKE_NOTES)
    resolve_motor_row(wb)
    add_magnetic_sensor_row(wb)
    annotate_amperage(wb)
    update_legend(wb)

    # Holding Brake sits after Shaft Sensor: both describe what hangs off the
    # motor shaft, and a build walks them together.
    order = [
        "Legend",
        "Voltage",
        "Amperage",
        "Motor",
        "Shaft Sensor",
        "Holding Brake",
        "Protocol",
        "Control",
        "EMI Hardening",
        "Wire Egress",
        "Form Factor",
    ]
    wb._sheets = [wb[n] for n in order if n in wb.sheetnames] + [
        wb[n] for n in wb.sheetnames if n not in order
    ]

    print(f"sheets before: {before}")
    print(f"sheets after:  {wb.sheetnames}")
    if args.dry_run:
        print("dry run -- nothing written")
        return 0

    stamp = datetime.now(timezone.utc).strftime("%Y%m%dT%H%M%SZ")
    backup = WORKBOOK.with_suffix(f".xlsx.{stamp}.bak")
    shutil.copy2(WORKBOOK, backup)
    wb.save(WORKBOOK)
    print(f"backed up  {backup.name}")
    print(f"wrote      {WORKBOOK}")
    return 0


if __name__ == "__main__":
    raise SystemExit(main())

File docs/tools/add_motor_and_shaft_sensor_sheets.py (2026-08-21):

#!/usr/bin/env python3
"""Add the Motor and Shaft Sensor axis sheets to docs/decision-matrix.xlsx.

Governed by AGENTS.md. The workbook shipped with five axis sheets (Voltage,
Amperage, Protocol, Control, EMI Hardening), but a build cannot actually be
instantiated from it without two more:

  * **Motor** -- brushed vs brushless. This is NOT a parameter tweak. It
    changes the bridge topology, the switch-position count, the gate-driver
    PART NUMBER and the shunt count. A 3-phase gate driver cannot drive an
    H-bridge as-is.
  * **Shaft Sensor** -- sensorless / Hall / quadrature encoder / resolver.
    Drives the MCU pin budget, the connector, and whether an extra IC
    (a resolver-to-digital converter) joins the BOM at all.

See docs/solutions/architecture-patterns/esc-build-instantiation-workflow.md
for why these two are the axes that were missing.

WHAT THIS SCRIPT WILL NOT DO
-----------------------------
It does not invent part numbers. AGENTS.md Sec.1.3 forbids filling a cell with
a plausible-sounding part, and several cells below genuinely have no verified
answer in this repo yet:

  * No H-bridge gate driver has been sourced or verified here. The brushed
    row's driver cell is `Open / unresolved`, not a guess.
  * No resolver-to-digital converter has been sourced or verified.
  * No Hall-sensor part has been verified. The Control sheet already names
    TI DRV5013 as a *fallback candidate* for its sensorless rows, so that
    name is carried across as a candidate, with its existing status, rather
    than promoted.

Every such cell reads `TBD -- requires primary-source verification
(AGENTS.md Sec.1.3)` and carries status `Open / unresolved`. That is the
correct state for this workbook, not a defect in it.

The script is idempotent: re-running replaces the two sheets rather than
duplicating them, and it backs the workbook up first.

Requires: pip install openpyxl

Usage:
    python3 docs/tools/add_motor_and_shaft_sensor_sheets.py [--dry-run]
"""
# Authored by Claude Opus 5 (Anthropic) 2026-08-16. AI-generated; part
# selections are carried from this repo's own verified records or explicitly
# left open. Not human-authored.

import argparse
import shutil
from datetime import datetime, timezone
from pathlib import Path

import openpyxl
from openpyxl.styles import Alignment, Font, PatternFill

REPO = Path(__file__).resolve().parents[2]
WORKBOOK = REPO / "docs" / "decision-matrix.xlsx"

HEADER_FILL = PatternFill("solid", fgColor="FF2F5597")
HEADER_FONT = Font(bold=True, size=10, color="FFFFFFFF")
TITLE_FONT = Font(bold=True, size=16)
SUB_FONT = Font(size=10)
BODY_ALIGN = Alignment(wrap_text=True, vertical="top")
HEADER_ALIGN = Alignment(wrap_text=True, vertical="center")

TBD = "TBD -- requires primary-source verification (AGENTS.md Sec.1.3)"

# ---------------------------------------------------------------- Motor -----
MOTOR = {
    "title": "Motor Type Decision Matrix",
    "subtitle": "Build axis: Motor (Brushed / Brushless)",
    "widths": [18, 26, 14, 34, 24, 14, 34, 18, 22],
    "columns": [
        "Motor Type",
        "Bridge Topology",
        "Switch Positions",
        "Gate Driver Part",
        "Output Terminals",
        "Shunt Qty",
        "Commutation Requirement",
        "REFERENCES.md Tags",
        "Status",
    ],
    "rows": [
        [
            "Brushless (BLDC / PMSM)",
            "Three half-bridges (3-phase inverter)",
            "6 (3 high + 3 low)",
            "TI DRV8353S, 3-phase smart gate driver, SPI variant [21]",
            "3 (PH_A / PH_B / PH_C)",
            "3 (one per phase, low-side)",
            "Six-step trapezoidal or FOC; rotor position from the Shaft Sensor axis",
            "[21]",
            "Verified (local PDF)",
        ],
        [
            "Brushed (DC)",
            "Single H-bridge",
            "4 (2 high + 2 low)",
            TBD + ". No H-bridge gate driver has been sourced or verified in "
            "this repo. NOTE, not yet vetted: a 3-phase driver such as the "
            "DRV8353S [21] can drive an H-bridge by using two of its three "
            "half-bridges and leaving the third unused -- this reuses an "
            "already-verified part at the cost of wasted silicon and board "
            "area, and must be checked against [21] before adoption.",
            "2 (M+ / M-)",
            "1-2 (bridge-leg or in-line)",
            (
                "None -- direction and magnitude set by bridge polarity and duty "
                "cycle; no rotor position needed for basic operation"
            ),
            "-",
            "Open / unresolved",
        ],
    ],
}
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

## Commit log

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2026-08-02 Add design-option decision-matrix spreadsheet
    Adds docs/decision-matrix.xlsx: one sheet per README.md build axis
    (Voltage, Amperage, Protocol, Control, EMI Hardening), each row a build
    option with its workflow steps, BOM component(s), REFERENCES.md
    citation tags, and a verification status (Verified/Candidate/Open/No
    part needed). Voltage and Amperage sheets use live formulas (pack
    voltage from per-cell assumptions; shunt power/qty from tier current)
    rather than hardcoded results, so they recalculate if the underlying
    assumptions change. Cross-checked against REFERENCES.md [12]-[23].
    Claude-Session: https://claude.ai/code/session_01EjgH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
    [decision-matrix.xlsx]
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2026-08-02 Fix CI failures: invalid KiCad file structure, lint, markdown
    The generated .kicad_sch failed to load in real KiCad ("Failed to load
    schematic file"): the wire helper emitted 3-point polylines for L-shaped
    routes, but KiCad's schematic `wire` token only supports a single
    straight 2-point segment (unlike PCB graphic lines). Installed KiCad
    7.0.11 locally (kicad-cli / pcbnew) to reproduce and fix this -- routes
    now emit one wire object per straight leg. Verified by bisecting the
    177 original wire objects down to the exact offending one, then
    confirming `kicad-cli sch export svg/netlist` succeed end-to-end.
    The generated .kicad_pcb also failed to load: the Faraday-shield
    mechanical-placeholder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
    [open_secure_esc_6s_50a_can485_faraday.kicad_pcb, open_secure_esc_6s_50a_can485_faraday.kicad_sch]
2026-08-02 Fix ERC power-pin-not-driven violations and ruff/CI version mismatch
    CI's ERC check (real KiCad 9.0 via kicad-cli sch erc) flagged 8 error-
    severity violations: every rail that's carried only by same-name global
    labels with no regulator/source symbol on the sheet (GND, 3V3, VM, the
    two isolated-transceiver grounds, the two open isolated-supply nets)
    plus DRV8353S.VREF (wired only to its own decoupling cap, no label at
    all) has power-input pins with no declared driver. Added a PWR_FLAG
    generic part (genlib.py power:PWR_FLAG) and placed one on each of those
    8 nets -- KiCad's standard mechanism for "this net is intentionally
    driven from outside this schematic," not a claim about where the power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
    [open_secure_esc_6s_50a_can485_faraday.kicad_pcb, open_secure_esc_6s_50a_can485_faraday.kicad_sch]
2026-08-02 Mark PWR_FLAG as a real KiCad power symbol, add junctions at flag points
    The previous PWR_FLAG fix (a55207f) didn't reduce ERC's violation count
    -- it went from 8 to 11. My PWR_FLAG instances had a power_out-typed
    pin but were built through the same generic-symbol path as the R/C/
    connector stand-ins, which never sets the library symbol's own `(power)`
    token. Real KiCad's power-input-pin-not-driven ERC check looks for that
    token (how its own power:GND/power:PWR_FLAG etc. are authored), not just
    a power_out pin sitting on an ordinary symbol -- so none of the 8 flags
    actually counted as drivers, and the 3-symbol-count increase likely
    added its own new findings on top.
    load_generic_symbol() no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
    [open_secure_esc_6s_50a_can485_faraday.kicad_sch]
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2026-08-02 Fix wire-routing shorts: ERC's pin_to_pin violations were real, not power-flag noise
    The real cause of ERC's 8 (then 11) violations was never the power-flag
    work -- it was a routing bug in Builder.wire()'s naive 2-segment L-route.
    Its first leg reused the source pin's native row/column and its second
    leg the destination's; both are shared by every sibling pin in the same
    stack (all of DRV8353S's top-row pins share one Y, every pin on a
    component's right edge shares one X). Whenever two unrelated wires'
    long traversal fell on one of those shared coordinates, KiCad correctly
    read the collinear, overlapping segments as one net -- an actual short
    between signals like DRV8353S's GHA/GLA/GHB gate-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
    [open_secure_esc_6s_50a_can485_faraday.kicad_sch]
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2026-08-03 Migrate MCU to NXP S32K144, drop SLB9672 TPM in favor of on-chip CSEc
    Replaces the project MCU (MSPM0G3507) with the NXP S32K144, whose on-chip
    CSEc (Cryptographic Services Engine, SHE-compliant) security module now
    provides message authentication in place of the discrete Infineon SLB9672
    TPM, which is removed from the design entirely.
    - REFERENCES.md: add [31] (S32K1xx Data Sheet, local copy verified against
    CSEc, packages, memory, power-pin names, RESET_B/SWD_CLK/SWD_DIO); mark
    [1] and [2] superseded/dropped rather than repurposed, per AGENTS.md.
    - symbols/specs/S32K144.json + symbols/S32K144.kicad_sym: new MCU symbol.
    Feature-level facts VERIFIED against the local datasheet; physic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
    [open_secure_esc_6s_50a_can485_faraday.kicad_pcb, open_secure_esc_6s_50a_can485_faraday.kicad_sch]
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2026-08-10 docs: record the secure element across README, build BOM, TODO, and REFERENCES
    Propagates the U2 OPTIGA Trust M addition into the documentation layer and
    closes two citation defects found along the way.
    README.md / builds/6s/50A/CAN_485_faraday/README.md: state the root of trust
    explicitly and add the Trust M, its two 10k pull-ups and its 100 nF decoupling
    cap to the build BOM with citations. Both make the same point the symbol
    metadata makes -- this is a secure element, NOT a reinstated TPM -- and both
    flag that the land pattern is an IPC-7351-style derivation rather than an
    Infineon recommendation, since [45] publishes none.
    REFERENCES.md: **adds the missing [44] entry.** The catalog jum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
    [gen_schematic.py]
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2026-08-16 Take 6S/50A build to ERC-clean, add two decision-matrix axes, start 30x60 respin
    Handoff commit. The schematic is finished and verified; PCB placement is not,
    and is where the next session starts (TODO.md 12.5.j).
    FOUR REAL ELECTRICAL DEFECTS FIXED (not tidying)
    * Gate-driver SPI reads could never have worked. REFERENCES.md [21] gives
    DRV8353S SDO (pin 27) as type OD -- "This pin requires an external pullup
    resistor". There was none. Added R14, mirroring R11 on nFAULT.
    * The board had no battery input. VM reached C1/C6/R8/U5 and three MOSFET
    drains and no connector; the old PCB had a J5 footprint with no schematic
    counterpart, i.e. two netless pads.
    * Four isolated-side power flags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
    [decision-matrix.xlsx, open_secure_esc_6s_50a_can485_faraday.kicad_pcb, open_secure_esc_6s_50a_can485_faraday.kicad_sch]
2026-08-16 Answer conductor sizing from physics; find a GND-to-VM short in the placement
    CONDUCTOR SIZING (12.5.p). docs/tools/conductor_sizing.py derives phase-pour
    resistance and dissipation from copper's resistivity and geometry. Result:
    2 oz outer copper is the floor. At 1 oz the three 7.5x22 mm phase pours
    dissipate 13.3 W at 50 A, against 10.5 W of conduction loss from all six
    TPHR8504PL FETs -- the copper would be the dominant heat source on a board
    whose reference design [47] already measures 103 C at this current.
    This is an AGENTS.md Sec.4 engineering derivation from material constants, in
    the same form as the build's existing Faraday-tier field-strength derivation.
    It yields WATTS, not degr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
    [conductor_sizing.py]
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2026-08-16 Route the signal nets; give VM real copper instead of the router's 3 mm track
    FreeRouting 2.2.4, 100 passes, 15 min 26 s: 124 unrouted -> 56, laying 381
    segments and 48 vias. Then 29 of those segments were deleted on purpose.
    The router closed VM with 3.0 mm track from the "power" net class, which is
    the 5.2 W outcome the previous commit predicted. strip_high_current_tracks.py
    removed them; add_vm_top_pour.py replaced them with 235.1 mm^2 of F.Cu VM
    pour over y 0.60..15.50, priority 2 -- below the phase pours (3) so they keep
    every square they own, above the F.Cu GND pour (0), which had nothing to do in
    that band. Pad connection FULL: thermal spokes are for solderability on small
    pads, and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
    [open_secure_esc_6s_50a_can485_faraday.kicad_pcb]
2026-08-17 Repair the front/back re-placement: unbend the phases, rebuild the stale copper
    The repo owner restructured the board so the front carries power (pack ->
    FETs -> phase terminals) and the back carries control and comms, with comms
    and pack input at the same end. That is the right structure and it is what
    finally opens the F.Cu corridor U3/U4 used to block -- 12.5.t's blocker.
    Four mechanical consequences, all with one right answer, applied by
    tools/fix_after_replacement.py:
    1. PH_A AND PH_C WERE CROSSED. J4A sat at x 21.6 while Q1/Q2 sat at
    x 2.2-6.0, and J4C was the mirror -- 19.4 mm of lateral span each, with
    two 50 A nets having to cross one another. Swapped the terminals; al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
    [open_secure_esc_6s_50a_can485_faraday.kicad_pcb]
2026-08-17 Read the isolator datasheets: the keepout is backwards, and creepage fails
    The repo owner rotated U3 by 180 deg, which closes 12.5.aa -- U3's isolated
    row now sits at x 11.28 facing J2, so the CAN runs are 0.05 and 2.59 mm
    instead of 9.35 and 11.89. U4/J3 was already correct.
    That left "what do we do about the keepout". Rather than guess, went to the
    primary sources already in docs/datasheets/.
    THE FULL-WIDTH 4-LAYER KEEPOUT IS NOT WHAT ANALOG DEVICES ASKS FOR. [9] p.17,
    for a four layer board, asks for the OPPOSITE: "place an embedded stitching
    capacitor between GND1 and GND2 using internal layers of the PCB planes ...
    This capacitor provides a return path for high frequency common-mode n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
    [open_secure_esc_6s_50a_can485_faraday.kicad_pcb]
2026-08-18 Fit the isolated-supply ferrites -- which fixes a supply that was never wired
    Asked to integrate the Murata bead the repo owner supplied. Reading the two
    isolator pin tables first turned this from an EMC improvement into a defect
    fix: the isolated side of BOTH transceivers was unwired.
    CAN_VISOOUT U3.19 only dangling
    CAN_VISOIN_OPEN U3.16 only dangling
    CAN_ISO_GND U3.11,12,15,18,20 all merged
    RS485_VISOOUT U4.12 only dangling
    RS485_VISOIN_OPEN U4.19 only dangling
    RS485_ISO_GND U4.11,14,16,20 all merged
    [10] p.15: "Connect this pin through a ferrite bead and short the PCB trace to
    VISOIN FOR OPERA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
    [open_secure_esc_6s_50a_can485_faraday.kicad_pcb, open_secure_esc_6s_50a_can485_faraday.kicad_sch]
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2026-08-18 Shrink J1 to a 1.27 mm probe pattern: 36.0 -> 12.0 mm2
    J1 is the SWD debug port (SWDIO/SWCLK to U1.12/U1.13, plus 3V3 and GND). It
    was using the same 2.54 mm wire-solder pads as J2/J3, which it does not need:
    gen_smd_solder_pad_footprints.py already argued "For J1 (SWD) this is fine --
    it is a bring-up/debug interface, not a flight connection."
    was SolderPad_1x04_SMD_P2.54mm 9.22 x 3.20 mm, 36.0 mm2
    now SolderPad_1x04_SMD_P1.27mm_Probe 4.71 x 1.80 mm, 12.0 mm2
    1.27 mm is the pitch standard pogo-pin debug jigs use, so an off-the-shelf
    4-pin inline fixture fits, and staying single-row keeps that fixture trivial.
    A 2x2 grid would have saved a further ~2.5 mm2 but needs a c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
    [open_secure_esc_6s_50a_can485_faraday.kicad_pcb, open_secure_esc_6s_50a_can485_faraday.kicad_sch]
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2026-08-19 Capture the isolation-geometry learning, with the calculation to automate it
    The repo owner asked that this session's problems be captured and automated so
    other builds instantiate them instead of rediscovering them. This is the
    highest-cost one: creepage was treated as a DRC-time check, when it is a
    geometry constraint that decides the board's aspect ratio. Treating it as a
    check cost several complete re-placements, a board-growth attempt, and two
    reverts, all of which one line of trigonometry would have avoided.
    docs/tools/isolation_envelope.py
    Answers "can the widest non-isolated part sit BETWEEN the two isolated
    rows?" and prices the alternative. Parameterised by creepage,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
    [isolation_envelope.py]
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2026-08-19 Clean up placement rows and columns, measured rather than eyeballed
    The owner asked for row/column cleanup optimising electrical quality,
    scriptability and visual order. Built a measurement harness first --
    tools/score_placement.py -- so each change could be kept or reverted on a
    number. Four experiments, serial, logged to disk after each.
    baseline final
    DRC electrical 402 0
    on 0.5 mm grid 81.4% 100.0%
    distinct rows 34 30
    distinct columns 28 23
    sharing a row/column 69.5% 78.0%
    isolated lead max 9.94mm 8.73mm ([9] p.17 caps this at 10)
    creepage min 2.74mm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
    [open_secure_esc_6s_50a_can485_faraday.kicad_pcb]
2026-08-19 Owner's U1/U5 swap clears creepage for the first time: 3.98 -> 7.68 mm
    Measured with tools/score_placement.py against the previous best.
    before after
    creepage min 3.98mm 7.68mm PASSES (needs 7.5)
    gate loop max 22.32mm 16.83mm
    commutation 17.41mm 17.97mm
    DRC electrical 0 0
    distinct rows 30 37
    alignment 78.0% 69.5%
    The swap moved U5 into the shield centred under the FET array (y 33.10 in a
    23.62..44.08 span) and moved U1 clear to y 49.10, which is what opened the
    isolation room. U2 also went inside the shield. Verified the README's
    shortest-gate-loop constraint still holds -- U5 is under the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
    [open_secure_esc_6s_50a_can485_faraday.kicad_pcb]
2026-08-19 Fix a bug in my own creepage harness: it measured centres, not edges
    The harness compared pad CENTRES. Creepage and clearance are defined between
    the nearest points of two conductors -- edge to edge. Centre-to-centre
    overstates the gap by roughly half a pad on each side, which on a 7.5 mm
    requirement is the entire margin.
    Every creepage number reported from this harness was therefore optimistic,
    including the "7.68 mm, PASSES" result attributed to the U1/U5 swap. Corrected:
    pair edge-to-edge centre-to-centre (wrong)
    C14.2 <-> SH1.1 2.51 mm 10.69 mm
    U4.11 <-> J5B.1 2.80 mm 8.60 mm
    C18.1 <-> SH1.1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
    [open_secure_esc_6s_50a_can485_faraday.kicad_pcb]
2026-08-19 Lengthen to 66.1 mm: the shield now clears the isolated section
    SH1 is a GND conductor with 77.6 mm of perimeter sitting under the isolated
    support columns, and it was the dominant creepage offender at 1.98 mm against
    [9] Table 6's 7.5 mm. Moving the power/control block down 6.00 mm clears it:
    SH1 no longer appears among the closest isolated-to-non-isolated pairs at all.
    board 32.00 x 60.10 -> 32.00 x 66.10 mm
    creepage min 1.98 -> 2.80 mm
    binding pair C14/C18<->SH1 -> U4.11 <-> J5B.1
    DRC electrical 0
    isolated lead max 9.31 mm (limit 10)
    gate loop ma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
    [open_secure_esc_6s_50a_can485_faraday.kicad_pcb]
2026-08-19 Check the PCB skills for IPC-2152: neither has it, and one misattributes 2221
    The repo owner pointed at pcb-engineer and pcb-designer as holding IPC-2152
    reference tables. Read both. Neither does.
    pcb-engineer/references/design-rules.md prints
    Area = (I / (k x dT^0.44))^(1/0.725), k = 0.048 external / 0.024 internal
    under the heading "the IPC-2152 formula". Those are IPC-2221 Appendix A
    constants, inherited from IPC-D-275. IPC-2152 replaced those curves BECAUSE
    they were found inaccurate, and it publishes charts rather than a closed-form
    k/b/c. conductor_sizing.py already recorded this in August; this run
    quantifies it.
    The document also disagrees with itself, and the error grows wi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
    [open_secure_esc_6s_50a_can485_faraday.kicad_pcb]
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2026-08-19 Creepage 7.51 -> 7.98 mm: the ceiling was my formula, not the board
    The repo owner pushed back on two assertions and both were wrong.
    FIRST: I claimed the FET columns could not move inboard because SH1's land is
    a fixed 22.20 mm and they must sit within it. They already overhang it --
    Q1/Q2 by 0.75 mm, Q5/Q6 by 2.75 mm -- with 5.30 and 6.30 mm of slack between
    columns. The claim was asserted without checking.
    SECOND, AND THE REAL ONE: edge_path() computed insetA + thickness + insetB,
    which silently assumes two opposite-face parts sit at the same position ALONG
    the edge. They rarely do. The true creepage path is the unfolded surface
    distance,
    sqrt( along_edge_separation^2 + (insetA + t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
    [open_secure_esc_6s_50a_can485_faraday.kicad_pcb]
2026-08-19 Score connectivity too: the +/-1.0 mm spread was breaking GND
    Correcting the previous commit rather than leaving it standing. It applied a
    +/-1.0 mm transceiver spread and reported "DRC electrical 0". The DRC number
    was real; the conclusion drawn from it was not.
    score_placement.py read only kicad-cli's "violations" array. kicad-cli reports
    broken connections in a SEPARATE "unconnected_items" array, so the harness was
    structurally blind to them. Checking by hand:
    before the spread 159 unconnected
    after the spread 161 unconnected
    The +/-1.0 mm move severed two GND connections. Refilling the pour around the
    displaced parts fragments the B.Cu GND pour, and two of the eight newly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
    [open_secure_esc_6s_50a_can485_faraday.kicad_pcb]
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2026-08-19 Clean build pass: 78 -> 16 DRC violations, zero errors remaining
    The courtyard problem I reported turned out not to exist, so this addresses
    the violations the board actually has. Every error-severity violation is now
    resolved; all 16 remaining are warnings.
    drill_out_of_range 12 -> 0 (error)
    starved_thermal 11 -> 0 (error)
    isolated_copper 2 -> 1 (warning)
    silk_over_copper 35 -> 8 (warning)
    silk_overlap 18 -> 7 (warning)
    unconnected 159 -> 158
    Creepage holds at 7.83 mm, both isolation rules still PASS, DRC electrical 0.
    tools/fix_u5_thermal_vias.py
    U5's 12 GND thermal vias 0.400/0.200 -> 0.600/0.300 mm. Not a chosen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
    [open_secure_esc_6s_50a_can485_faraday.kicad_pcb]
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2026-08-19 Restore the island + silk fixes a concurrent KiCad save reverted
    CORRECTION TO e7c5171. That commit's message claims "78 -> 16 DRC violations,
    zero errors remaining". The measurement was real, but the file it describes is
    not the file it committed. Running DRC on e7c5171's own blob gives 56
    violations, not 16. 4ba392b carried the same regression forward.
    What happened: the repo owner had the board open in KiCad during the
    clean-build pass and saved it. KiCad wrote its in-memory copy, which had been
    loaded during the window when remove_vm_island.py had crashed on an LSET
    constructor and not yet been re-run -- so that save carried the via and
    thermal fixes but predated the island rule area an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
    [open_secure_esc_6s_50a_can485_faraday.kicad_pcb]
2026-08-19 Align, centre and symmetrize the layout; put U7/U8 on their own phases
    All geometry work is measured, and every move is reverted unless the harness
    says it cost nothing: DRC electrical 0, unconnected not rising, creepage not
    falling, isolated lead within 10.0 mm, gate and commutation loops not growing,
    both isolation rules still passing.
    RESULT
    phase pitch 10.500 / 10.500 mm (was 10.000 / 11.000)
    phase B exactly on the centreline x = 16.000
    mirror pairs 12 / 12 symmetric
    off the 0.5 mm grid 0 parts in x
    creepage 7.83 mm unchanged
    isolated lead 9.92 -> 9.76 mm improved
    commutation loop 19.60 -> 19.40 mm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
    [open_secure_esc_6s_50a_can485_faraday.kicad_pcb]
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2026-08-19 Verify the owner's U1/U5 centring; fix two defects it exposed
    The repo owner moved U1 and U5 with their surrounding components +1.000 mm in
    x, putting U1, U5 and SH1 exactly on the centreline. This is the move
    symmetrize.py refused (DRC electrical 1 and 28) -- and the guard was right
    about the tool's version, which moved the ICs ALONE. Moving each IC together
    with its supporting parts is a different move, and it passes.
    As saved the board showed 155 errors. All of them were stale zone fill; a
    refill clears every one. Same lesson as the J5B move: a GUI part move leaves
    the fill stale, so refill before judging the edit.
    Board after refill: 17 violations, all warning severity, DRC electrical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
    [open_secure_esc_6s_50a_can485_faraday.kicad_pcb]
2026-08-19 Assembly prep for professional reflow; correct the routing state
    The repo owner specified professional reflow assembly at JLCPCB or an
    equivalent house. That decides one open question and exposes several more.
    DECIDED: the five 0805 GND pads (C7 C9 C10 R5 R10) KEEP their solid zone
    connections, and fix_starved_thermals.py --skip-passives is not to be used on
    this build. A controlled reflow profile handles a solid 0805 GND bond; the
    thermal relief was only ever worth it to protect hand-soldering and rework.
    No change was needed -- the board was already in that state -- and TODO 12.5.ao
    now says so, so nobody reverts it later.
    CORRECTED, and it is the important one: THE BOARD IS NOT ROUTED.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
    [open_secure_esc_6s_50a_can485_faraday.kicad_pcb]
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2026-08-20 Routing pass: fix what the router was never told, and the pack return
    The board was found fully unrouted (0 tracks, 0 vias, 157 ratsnest). Getting
    it to route surfaced defects that were not routing defects, and every one of
    them made the route look BETTER, so no completion metric could have caught
    them.
    Fixed in the KiCad->Specctra->FreeRouting handoff (tools/autoroute.py):
    - net classes had vanished from the .kicad_pro, so VM, GND and all three motor
    phases would have routed at the 0.2 mm signal default. Now a hard stop.
    - two class net names no longer existed (renamed by the ferrite respin) and
    silently matched nothing. Now a hard stop.
    - KiCad exports every rule area as a TOTAL Specc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
    [open_secure_esc_6s_50a_can485_faraday.kicad_pcb]
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2026-08-31 fix(pcb): restore inner GND planes; add Wire Egress axis + same-end variant plan
    Inner copper planes are restored as the default. Rule area 7c9dc61f
    (x 20.75-51.15, y 76.50-86.55 mm) forbade `copperpour` on all four copper
    layers, cutting both inner GND planes across essentially the full board
    width at the terminal end.
    It was not needed there. The rule area is the isolation keepout, authored
    when the isolated transceivers U3/U4 sat at that end of the board; both are
    now at y 34.50 mm on B.Cu, so it guarded nothing where it stood. This repo
    had already recorded the problem three times without closing it: TODO.md
    12.5.z ("the keepout protects nothing"), 12.5.ae ("not datasheet-driven and
    sho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
    [decision-matrix.xlsx, open_secure_esc_6s_50a_can485_faraday.kicad_pcb]
2026-08-31 feat(build): 6S/50A/CAN-FD+RS-485/Faraday with same-end, opposite-face egress
    Instantiates builds/6s/50A/CAN_485_faraday_sameend/ for the
    `Wire Egress = Same-end, opposite faces` row of docs/decision-matrix.xlsx.
    All five 50 A conductors leave one board end: phases on F.Cu, pack on B.Cu,
    with the board's two inner GND planes between them as the interface shield.
    THE PLANNED PARTITION FAILED AND WAS NOT BUILT
    -----------------------------------------------
    docs/design-single-end-wire-egress-variant.md 3.3 originally moved U1/U2/J1
    to the logic end to clear the terminal end. Measured, U1's courtyard is
    13.45 mm, not the 12.90 mm the envelope calculation assumed, so with U1 at
    the logic end do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
    [open_secure_esc_6s_50a_can485_faraday_sameend.kicad_pcb, open_secure_esc_6s_50a_can485_faraday_sameend.kicad_sch]
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

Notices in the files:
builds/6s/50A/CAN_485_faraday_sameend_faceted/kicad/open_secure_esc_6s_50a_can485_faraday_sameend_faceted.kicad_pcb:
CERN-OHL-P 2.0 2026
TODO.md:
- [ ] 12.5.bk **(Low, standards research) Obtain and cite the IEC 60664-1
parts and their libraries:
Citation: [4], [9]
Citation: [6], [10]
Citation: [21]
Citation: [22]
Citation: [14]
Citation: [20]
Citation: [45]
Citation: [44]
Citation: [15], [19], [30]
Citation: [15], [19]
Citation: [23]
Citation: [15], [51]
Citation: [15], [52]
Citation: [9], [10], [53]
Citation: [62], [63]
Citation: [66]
